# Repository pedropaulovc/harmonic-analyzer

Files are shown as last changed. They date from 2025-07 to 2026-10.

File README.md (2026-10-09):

<h1 align="center">Michelson's Harmonic Analyzer</h1>

<p align="center">
  <em>Learn how to build the beautiful 19th century analog mechanical computer
  that performs Fourier synthesis and analysis via a system of gears, springs,
  levers, and cams. Interact with it in detail both physically and
  virtually.</em>
</p>

<table align="center">
<tr>
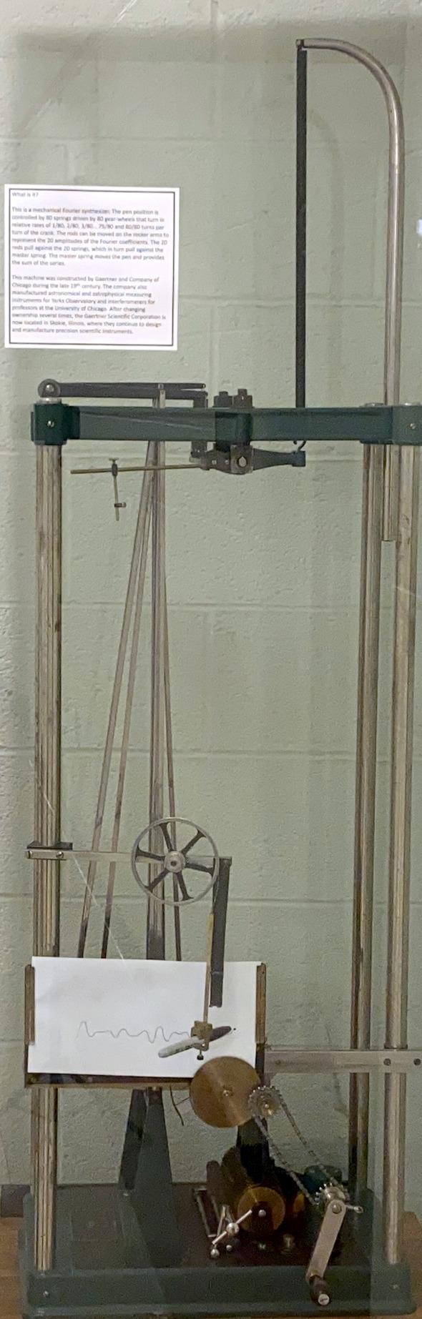
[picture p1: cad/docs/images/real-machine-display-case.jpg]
The surviving Michelson analyzer, stood on end in a glass case at the University of Illinois
<td align="center" width="50%"></td>
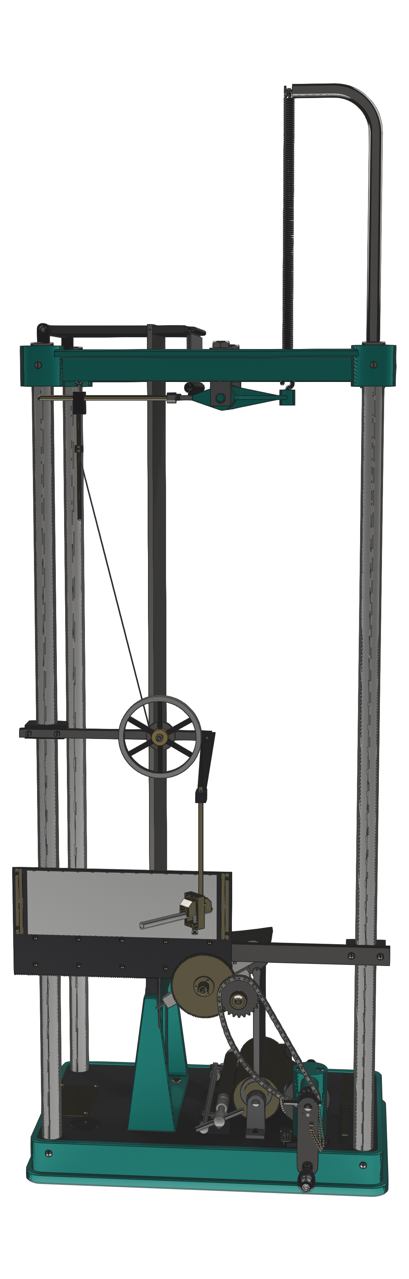
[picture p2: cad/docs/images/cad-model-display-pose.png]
The CAD reconstruction rendered in the same pose
<td align="center" width="50%"></td>
</tr>
<tr>
<td align="center"><sub><b>The machine.</b> The surviving 20-element analyzer, in a corridor case at the University of Illinois.<br>Photographed 2025-08-28.</sub></td>
<td align="center"><sub><b>The model.</b> 149 registered part families, generated from Python, gated on every build.<br>Same pose, rendered from the glTF this repository exports.</sub></td>
</tr>
</table>

<p align="center">
  <a href="cad/">CAD</a> ·
  <a href="book/README.md">The book</a> ·
  <a href="logbook/README.md">Learning</a> ·
  <a href="logbook/progress.md#parts-made">Manufacture</a> ·
  <a href="kickstarter/README.md">Kickstarter</a> ·
  <a href="web/README.md">Website</a> ·
  <a href="ai-story/README.md">Built with AI</a>
</p>
<p align="center">
  Current work and sequencing: <a href="https://github.com/users/pedropaulovc/projects/1">Harmonic Analyzer project</a>.
</p>

---

Turn the crank and the machine performs Fourier synthesis. Twenty weighted
cosines get summed by twenty springs pulling on a knife-edge lever, and a pen
draws the result as a continuous curve. Set it up differently and it runs the
operation backwards, doing Fourier analysis, which Michelson himself declined to
explain on the grounds that it "involves so much mathematics that I shall not
undertake it here."

One of these machines survives in a glass case at the University of Illinois,
and it is very well documented. Bill Hammack, Steve Kranz and Bruce Carpenter
photographed it, took it apart on camera, and published both a book and a
[four-part video series](https://www.youtube.com/playlist?list=PL2FF649D0C4407B30)
explaining exactly how it works. If you want to understand the machine, go read
theirs first. It is free.

What none of that gives you is a way to make one. No dimensioned drawings, no
tolerances, no stock list, no setups, no process. A beautifully explained
machine that nobody has written down how to build.

So: 149 registered part families modelled in SolidWorks, generated from Python, verified on every
build and checked against those same photographs. Plus a book being written to
turn all of that into chips on a shop floor.

## Where it ends up

The finished machine is being donated to
[Matemateca](https://matemateca.ime.usp.br/index_ingles.html), the mathematics
outreach collection at the Institute of Mathematics and Statistics of the
University of São Paulo. They put mathematical objects in front of the public
and in front of students, and they will use this one with middle and high
schoolers. The professor who runs the collection is on board.

It slots into a gap they already have. The collection includes a harmonograph,
Chladni plates, a piece on the harmonic series, one on sampling, and one on
gears, plus an adding machine and a slide rule. What it does not have is the
thing that ties the harmonics half and the analog-computing half together: a
machine that decomposes a curve into its frequencies while you watch.

There is also a line on their donations page that reads, in hindsight, like a
description of this project:

> As there is immense difficulty in finding a professional who can bring object
> theory to practice, the value becomes very variable for each idea. The
> simpler, the lower its cost, which makes it difficult to produce more complex
> parts.

That destination sets the engineering bar. The machine has to work, not
photograph well. A fourteen-year-old gets to turn the crank, and the pen has to
draw the right curve when they do.

## CAD model and drawing coverage

| Frame | Drive train | Channels (×20) | Summing |
|:---:|:---:|:---:|:---:|
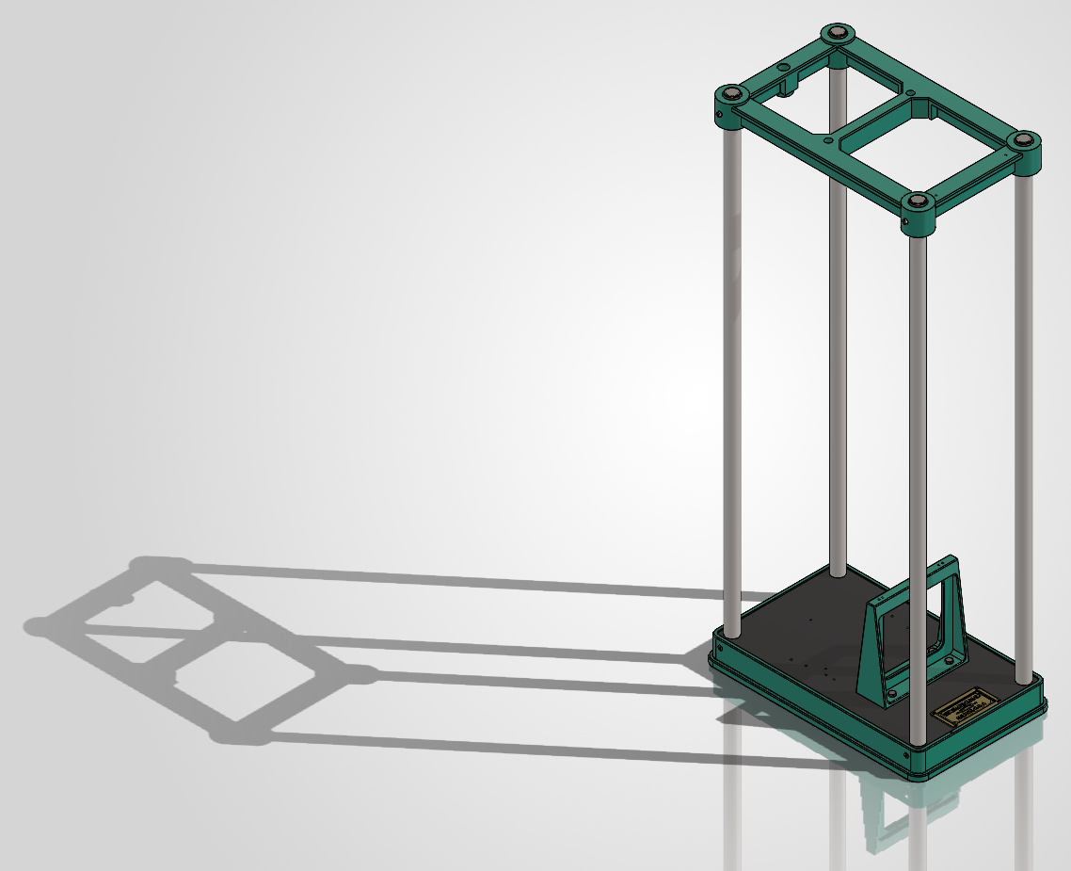
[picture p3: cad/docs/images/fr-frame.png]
Frame sub-assembly
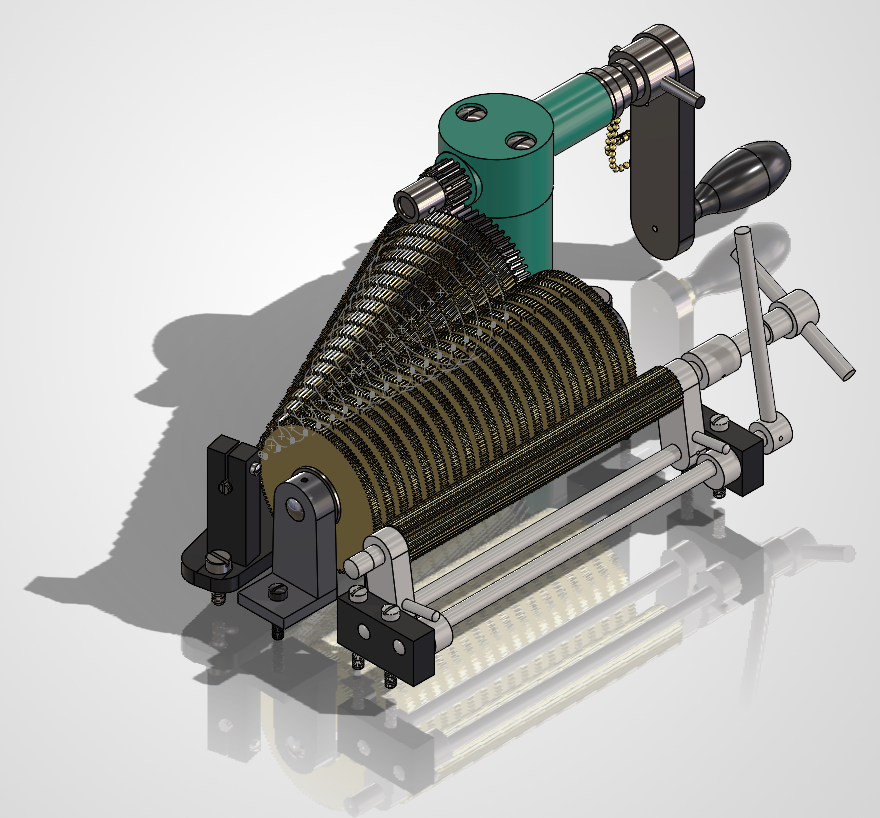
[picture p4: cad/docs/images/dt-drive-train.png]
Drive train: crank, cone gears, cylinder gears
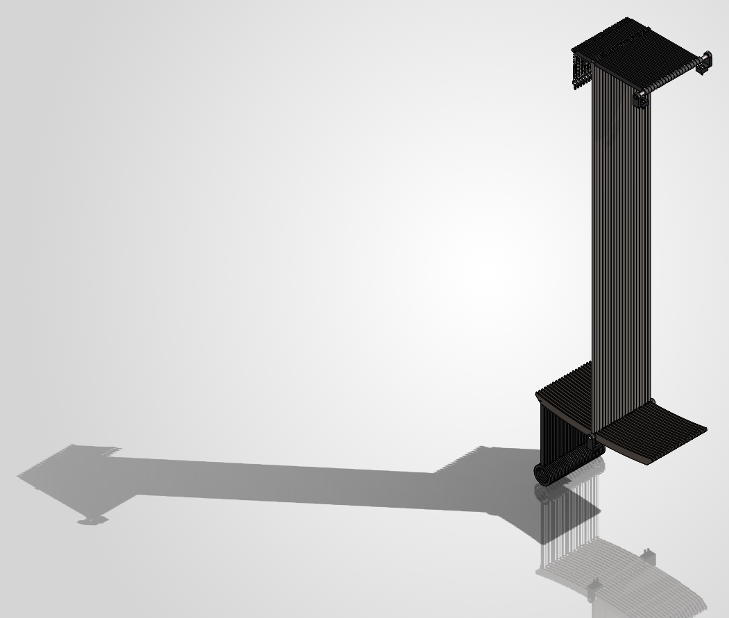
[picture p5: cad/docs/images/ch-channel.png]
Channel: rocker arms, amplitude bars, springs
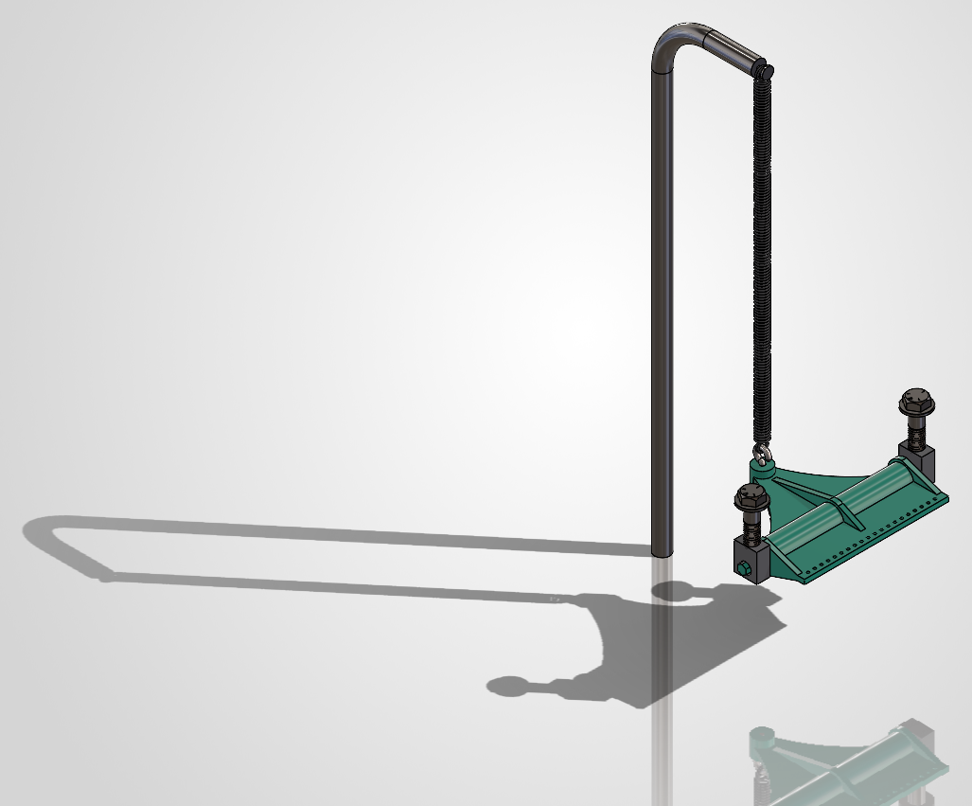
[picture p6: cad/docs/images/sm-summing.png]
Summing: knife-edge lever, counter-spring
|  |  |  |  |

| Magnifier | Pen | Paper drive |
|:---:|:---:|:---:|
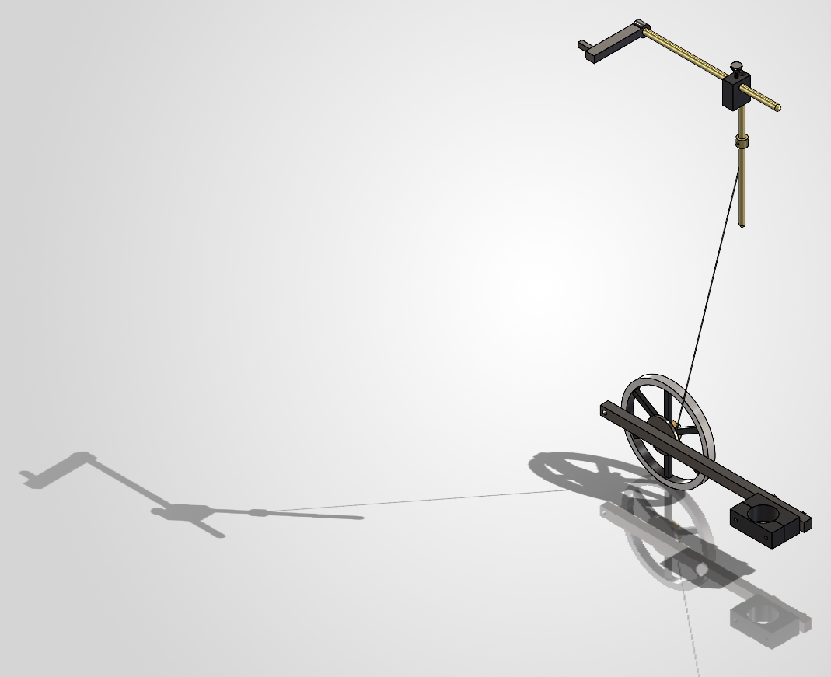
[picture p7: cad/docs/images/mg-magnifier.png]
Magnifier: magnifying lever and wheel
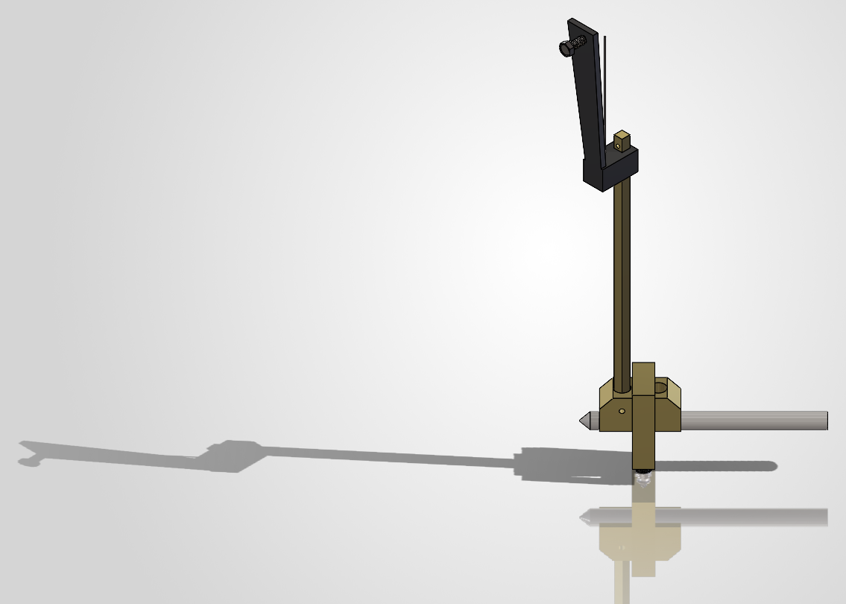
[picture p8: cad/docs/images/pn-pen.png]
Pen carriage
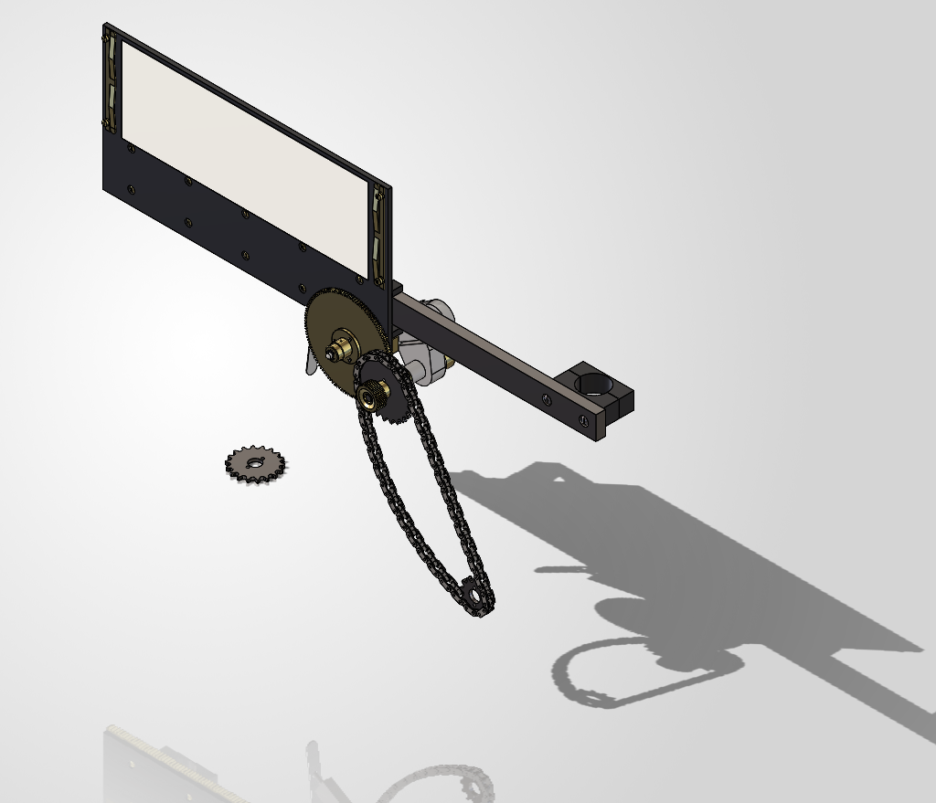
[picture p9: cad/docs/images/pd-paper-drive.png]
Platen, transgear, roller chain
|  |  |  |

Production drawings in the release bundle include both part sheets and
multi-sheet assembly drawings. Here are two part sheets and two assembly-sheet
examples:

| Rocker-arm support | Pinion arbor |
|:---:|:---:|
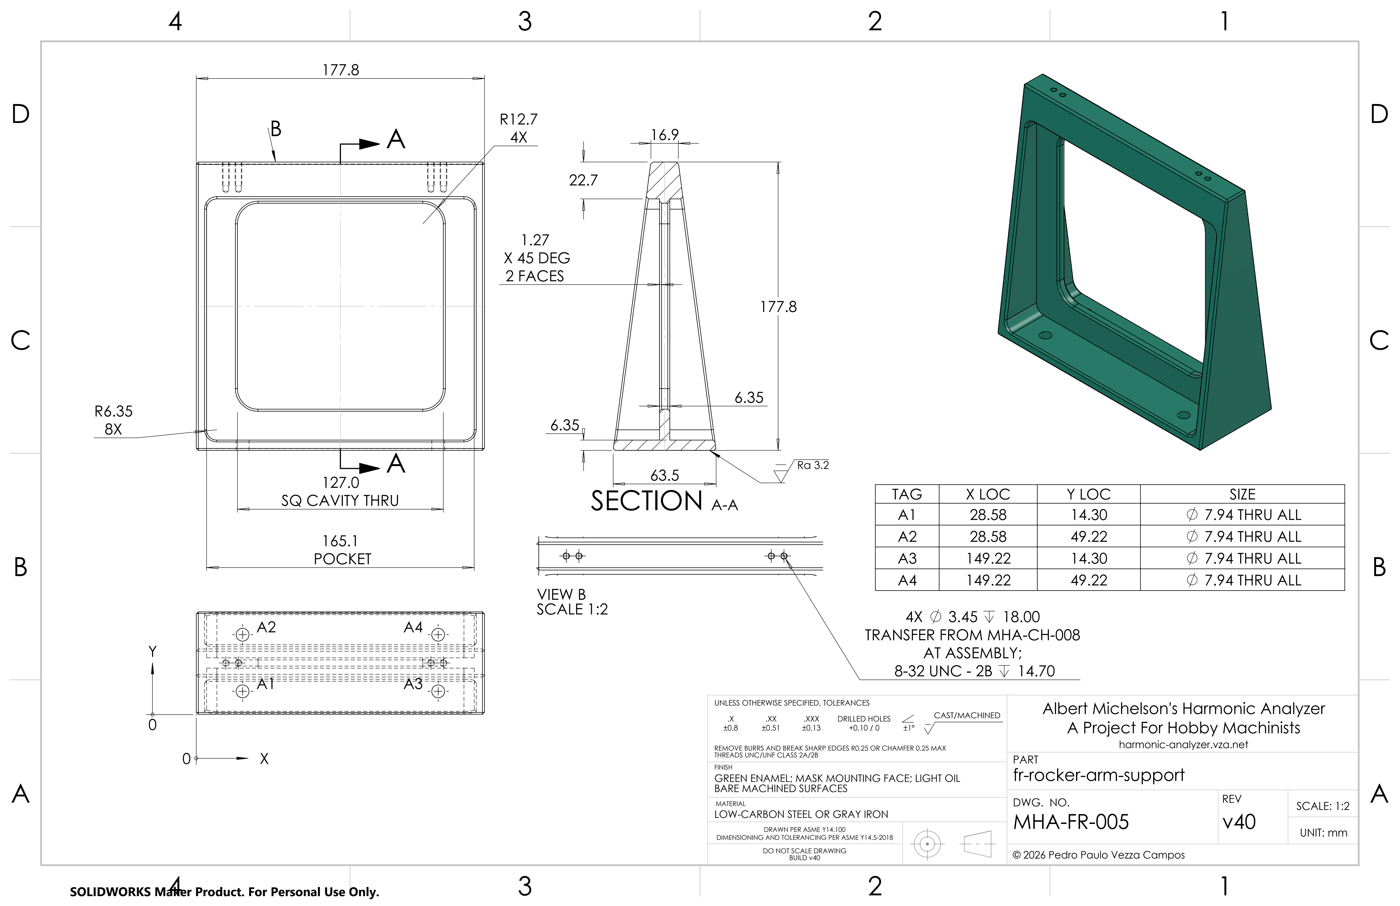
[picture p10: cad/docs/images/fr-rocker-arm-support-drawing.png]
Engineering drawing, rocker-arm support
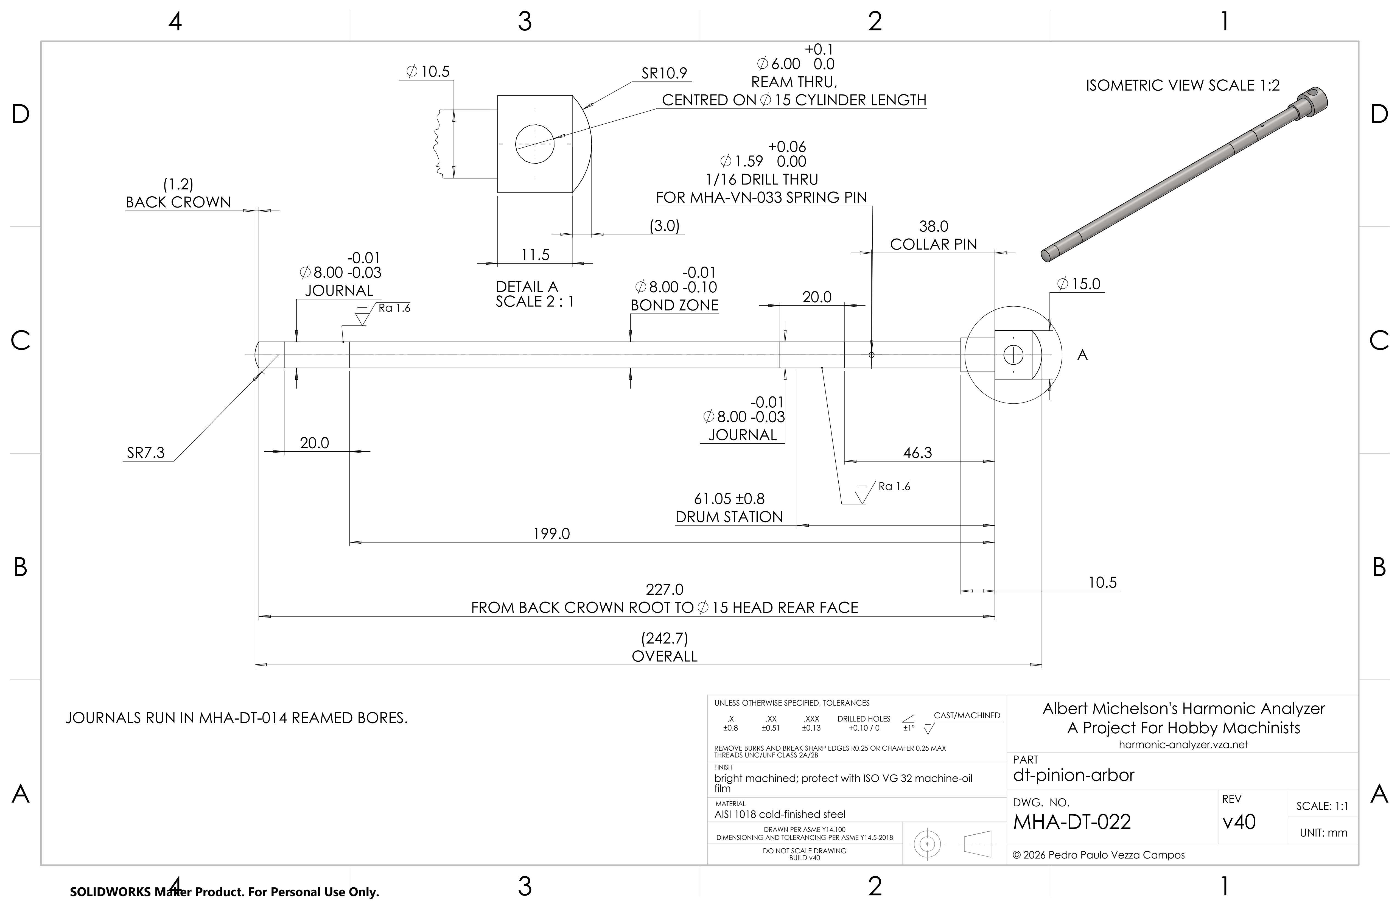
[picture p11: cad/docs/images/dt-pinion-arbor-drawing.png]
Engineering drawing, pinion arbor
|  |  |
| **Drive-train assembly, sheet 4:** Cone Set + Crank Exploded (v39, MHA-A03; now MHA-DT-000) | **Frame assembly, sheet 3:** Match-Fit and Assembly Sequence (v39, MHA-A04; now MHA-FR-000) |
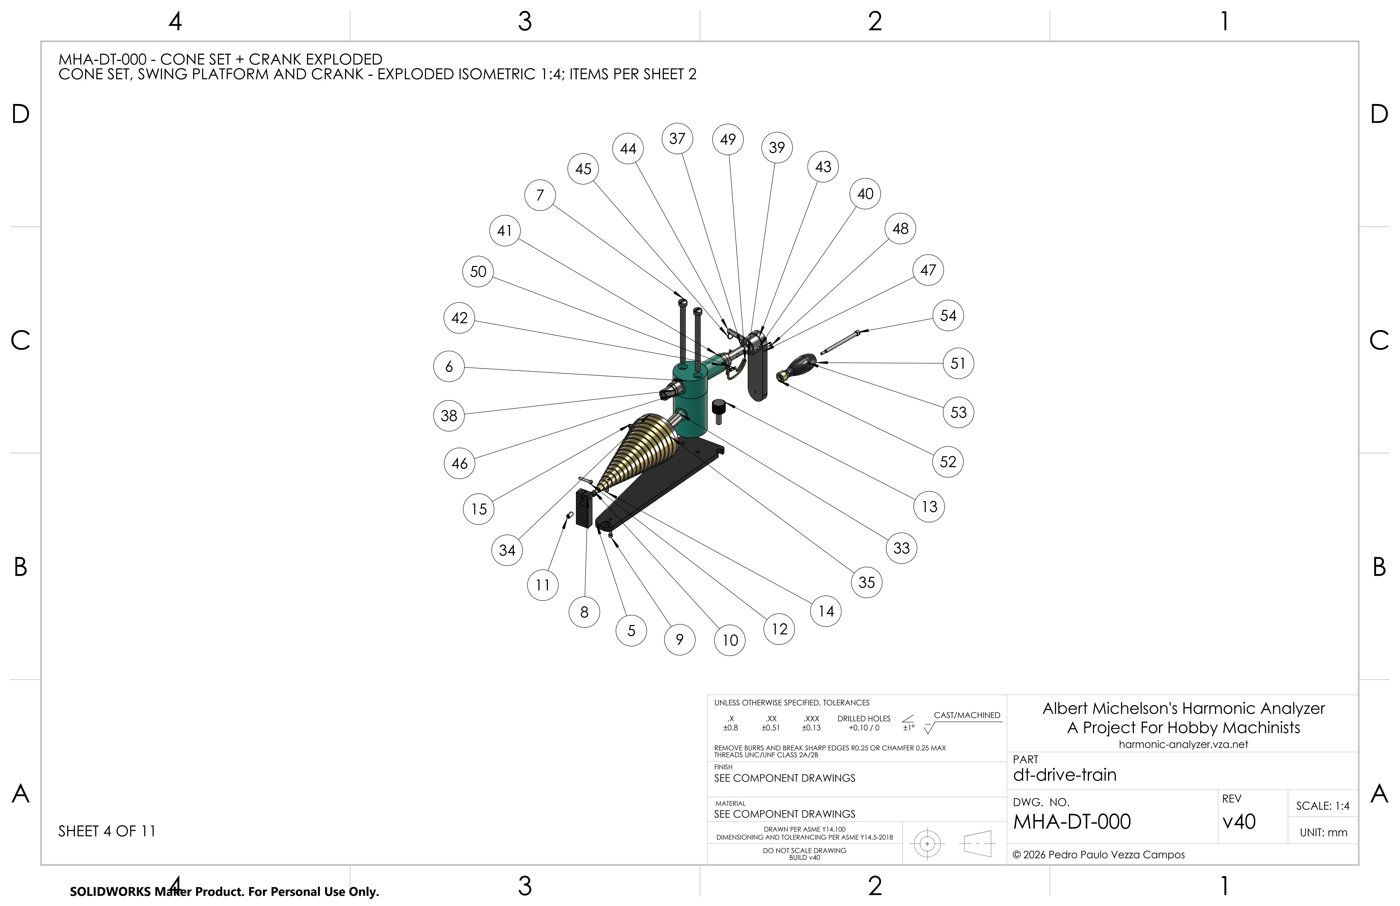
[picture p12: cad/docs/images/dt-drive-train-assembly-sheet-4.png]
Drive-train assembly drawing, sheet 4: Cone Set + Crank Exploded, v39 MHA-A03 (now MHA-DT-000)
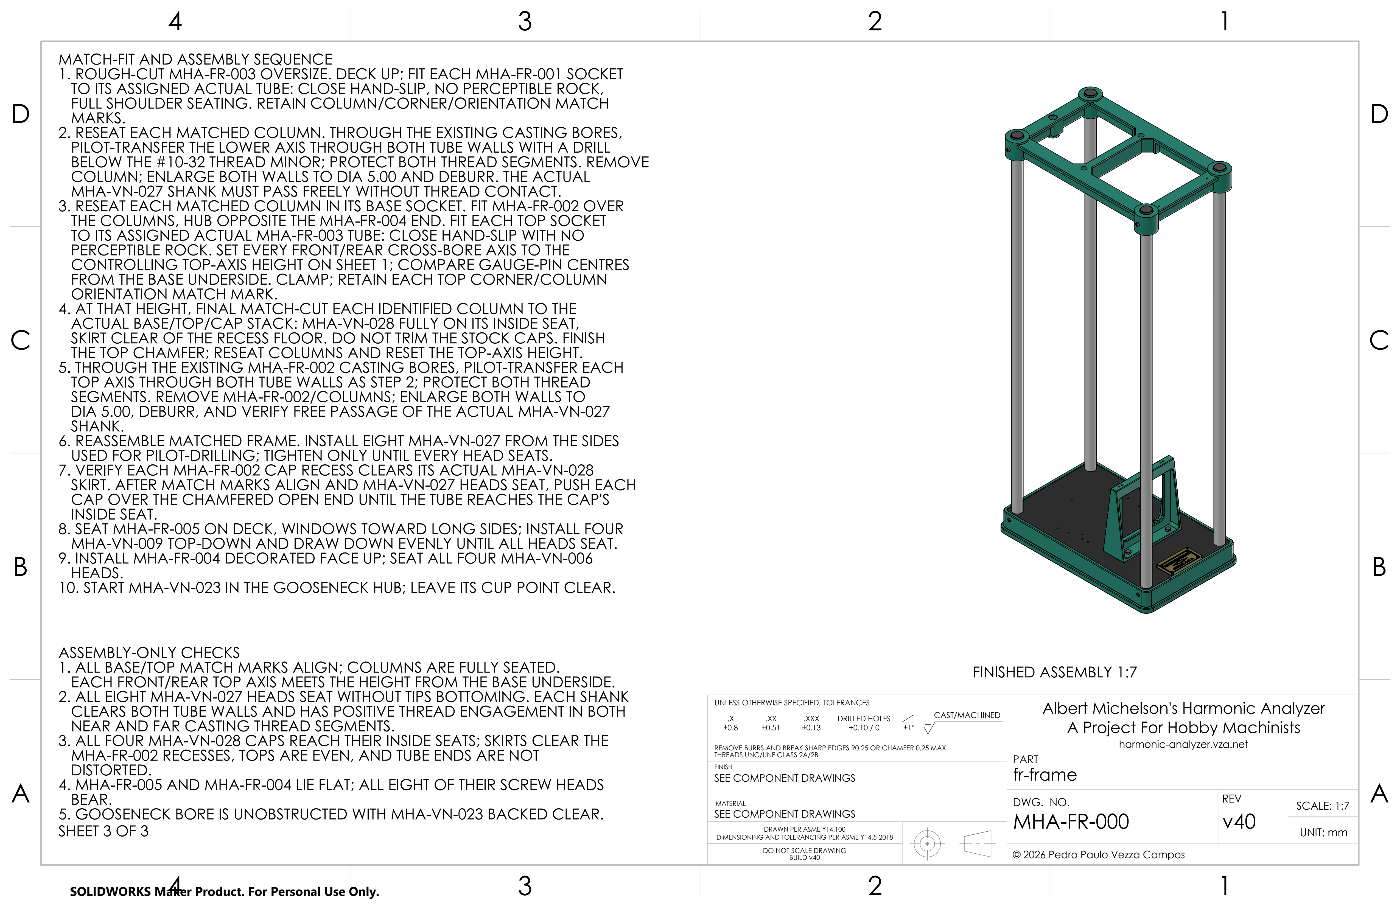
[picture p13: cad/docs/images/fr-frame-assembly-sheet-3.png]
Frame assembly drawing, sheet 3: Match-Fit and Assembly Sequence, v39 MHA-A04 (now MHA-FR-000)
|  |  |

Every part and assembly is generated by Python reproduction scripts in
[`cad/scripts/`](./cad/scripts) driving SolidWorks over its COM API. The scripts
are the source of truth. The `.sldprt`/`.sldasm` files and the renders are build
artefacts, regenerated by `doit` and snapshotted only at
[tagged releases](../../releases).

Every dimension traces back to a source (a book page, a photograph, or a
derivation) and carries a confidence level. Every assembly is gated on degrees
of freedom, interference and mass properties before it is allowed to save. And
the whole model gets scored against Hammack, Kranz and Carpenter's photographs
of the surviving machine, pair by pair, on every export.

Part and assembly filenames carry their subsystem prefix; drawing Numbers use
`MHA-<CATEGORY>-<NNN>`, with `000` reserved for each assembly. The
[subsystem identity guide and migration table](cad/docs/subsystem-identities.md)
defines current names and provides a lookup for identifiers in older releases
and bench records.

## Workstreams

Current portfolio status, priorities and sequencing live in the
[Harmonic Analyzer project](https://github.com/users/pedropaulovc/projects/1).
The repository files linked below hold the detailed engineering and publishing
facts.

| | |
|---|---|
| **[CAD](cad/)** | The generated SolidWorks reconstruction, production drawings, verification and releases. |
| **[The book](book/README.md)** | *A Project for Hobby Machinists*: every part, setup and cut on a manual mill and lathe. |
| **[Learning](logbook/README.md)** | Twelve modules of lathe and mill work, each ending with a real analyzer part. |
| **[Manufacture](logbook/progress.md#parts-made)** | The physical build: accepted quantities, scrap and the entries that record each shop session. |
| **[Kickstarter](kickstarter/README.md)** | Campaign, budget, rewards, assets and fulfilment for funding the build and book. |
| **[Website](web/README.md)** | The machine in a browser, driven by the exported CAD model. |
| **[Built with AI](ai-story/README.md)** | An evidence-backed account of using LLM agents for the project, failures included. |

## The hard parts, which are already identified

A per-part manufacturability pass ([`cad/docs/machining-dfm.md`](cad/docs/machining-dfm.md))
found three parts carrying essentially all of the risk:

- A six-tooth gear about 4 mm across with a 0.49 mm wall at the tooth root over
  a 0.79 mm bore. The hardest part in the machine, and not by a small margin.
- The knife edge, which is the precision interface of the whole instrument and
  sits on a hex trunnion cantilevered 21.7 mm off an organic cast lever.
- A Ø0.79 × 34 mm journal in steel, 43:1 slenderness. Whip city.

There is also one settled finding that shapes the entire build: off-the-shelf
involute cutters for this gear train's pitch do not exist. You make your own.

## Build the model yourself

You need a SolidWorks seat. Full instructions are in
[`cad/docs/BUILDING.md`](cad/docs/BUILDING.md).

```powershell
git submodule update --init --recursive
uv sync
uv run python -m doit          # every part + assembly + every gate
```

Without a seat you can still run the offline gates
(`uv run python -m doit check:math`), and every release ships the STEP, STL and
glTF exports plus the drawing PDFs.

Drawing-bound requirement manifests for the rocker arm, pivot shaft and cone
pivot post are exported with named STEP face sets. Their
`check:traveler_ch_rocker_arm`, `check:traveler_ch_pivot_shaft` and
`check:traveler_dt_cone_pivot_post` gates print the committed process plans through
[prechips](https://github.com/pedropaulovc/prechips); shop blockers are advisory
to this CAD gate, not permission to machine. See the
[export/traveler contract](cad/docs/pipeline/features-travelers.md).

## References

- Hammack, Kranz & Carpenter, *Albert Michelson's Harmonic Analyzer: A Visual
  Tour of a Nineteenth Century Machine that Performs Fourier Analysis*
  (Articulate Noise Books, 2014). Free to read, and the reason this project
  exists at all.
- engineerguy, ["A Machine That Uses Gears to Add Sines and Cosines"](https://www.youtube.com/playlist?list=PL2FF649D0C4407B30)
- Michelson & Stratton, "A New Harmonic Analyzer", *American Journal of Science*,
  fourth series 5, no. 25 (1898): 1–13.

This project is independent of those authors and the University of Illinois, and
is not endorsed by any of them.

## License

Code, CAD and documentation are [MIT](./LICENSE). Reuse of the source book's
content or the video transcripts has to respect their original copyright.

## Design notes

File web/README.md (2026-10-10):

# Harmonic analyzer video companion

Six engineerguy videos share an interactive view of the CAD-exported analyzer.
The original YouTube player sits in the model area's lower-right corner. Pause
for manual exploration, then orbit, pan, zoom, turn the crank or adjust the twenty
channels. Compact mode keeps the same visible player and its audio.

Website workstream status lives on the
[Harmonic Analyzer project](https://github.com/users/pedropaulovc/projects/1).
Implementation and fidelity limits are described in [`DESIGN.md`](DESIGN.md).

## Run locally

```sh
npm --prefix web ci
npm --prefix web run fetch-model -- /path/to/ha-harmonic-analyzer.glb
npm --prefix web run dev
```

The model is a generated artifact, absent from a fresh checkout. Use the exact
raw CAD export identified by `src/mechanics-data.ts`; incompatible bytes are
rejected. `fetch-model` projects native identities through the authoritative CAD
map, performs lossless exact deduplication and Meshopt compression, then publishes
only the optimized GLB. The approved raw export remains unchanged.
It also accepts `cad/out/gltf/ha-harmonic-analyzer.glb` when no path is supplied.
The raw cache stays outside public assets under `web/.vite/model-source/`.
Missing models and failed YouTube playback produce visible errors.

### Fresh-checkout tests and approved model cache

Use Node.js 22.12 or newer, npm and [uv](https://docs.astral.sh/uv/).
The fixture's exact archived CAD provenance commit,
`81539e53f5146c06a77541415bd79da673806d96`, must be available locally: use a
full clone or run `git fetch origin 81539e53f5146c06a77541415bd79da673806d96`.
From the repository root:

```sh
npm --prefix web ci
npm --prefix web run fetch-model:approved
cd web
node --test scripts/*.test.mjs
uv run --isolated --no-project --python 3.13 --with-requirements scripts/source-fit-requirements.txt python -m unittest discover -s scripts -p "test_*.py"
```

The Node command runs all web Node test files; the Python command runs all web
Python test files in an isolated environment with the source-fit dependencies.
These are tooling/geometry tests, not browser source-fidelity acceptance or CAD
builds. `uv` needs Python 3.13 and the listed packages available locally or
network access to install them.

`fetch-model:approved` downloads the already-approved optimized release GLB,
checks its native-source association, SHA-256 and exact byte length, and
atomically publishes it to
`web/.vite/deployment-model/<approved-optimized-sha256>.glb`. It requires network
access to GitHub and the exact approved SHA-named release asset to be published;
unavailable or mismatched bytes fail the command. It does not require deployment
commit/branch identity or Cloudflare credentials, build/deploy the site, or
regenerate raw-model metadata. It does not populate `public/models/` for local
browser use.

Native spring tests use this immutable-hash cache by default. Alternatively,
set `SPRING_MODEL_PATH` to a local file containing the exact approved optimized
GLB bytes before running the Node tests or `npm run test:performance` from
`web/`. Missing or incompatible geometry is an error, never a mock or skipped
test. A populated cache or this explicit path lets the spring tests run without
downloading the model again.

`npm run fetch-model` is different: it imports a **raw CAD export**, projects
identities and generates optimized output/native metadata as described above.
Do not pass the optimized release download to that importer or use it just to
prepare the spring-test cache. `npm run build:deploy` still downloads and
verifies the approved release before running `test:performance`, regardless of
an existing cache or `SPRING_MODEL_PATH`.

### Importing a future CAD release

To adopt a future approved CAD release, provide both its full commit and raw
SHA-256 (not the optimized file's hash):

```sh
npm --prefix web run fetch-model -- /path/to/new.glb --source-commit <full40hexapprovedCADcommit> --source-sha256 <approvedraw64hexreleasehash>
```

The release command reads that exact CAD revision, checks native rest geometry
and compatibility with the website's fixed kinematics, magnifier and spring
deformer mathematics, and stages new native metadata and the optimized asset.
Compatible geometry, rest, spring and setup changes are supported; unsupported
ratio, feed, native-rest association or spring-profile changes are refused with
a named parameter, preserving the last working assets. Missing revisions are
also refused.
A current source commit does not approve arbitrary bytes.
Native identity projection preserves parsed JSON numeric semantics, including
signed zero, and leaves binary geometry untouched. It does not preserve the
original JSON number spelling or integers beyond JavaScript's exact range.
Existing source tracks are stale for a new raw model and reject source-following;
manual exploration is not recalibration. See [`DESIGN.md`](DESIGN.md) for the
representation and provenance contract.

The current imported model is the approved **v39** release: raw SHA-256
`60a62a2edcd15012114d0234438ba54e24be5179f23751ac337cd6df205c562c`,
source commit `81539e53f5146c06a77541415bd79da673806d96`.
The original six source corpora remain archived and hash-sealed. Current v39
records reuse a subset of their measurements, not every historical landmark row.
Migrating those current records preserves their source pixels, PTS, hashes and
uncertainties while rebuilding release-specific tracks from `content/v39-source/`.
Further reuse requires exact exposure provenance and the same physical feature
under a current native association; an unchanged anchor ID alone is insufficient.
Old model-bound tracks remain incompatible, and approximate current tracks do
not establish source fidelity.
No complete current-release source-fidelity acceptance has been established.

Playback can start while the model or source track loads. Source-following starts
automatically when both are ready; pausing retains manual exploration. Status
announcements exclude the running clock. Force readouts are physical calculations,
not source measurements.

The public YouTube player keeps its existing playback and Restore clock contract.
The private local-original player uses visible app-owned play/pause, mute, volume,
scrub and exact-time seek controls. Its safe seek starts at an IDR verified from
the unchanged H264 access units and presents the requested original exposure;
it does not re-encode media or expose an unsafe browser-native timeline.
Local source selection and Restore bind the owned integer PTS/time base and
`requestVideoFrameCallback` frame to the retained authored sample. Native
`currentTime` remains the real model/draw timing clock, not an exact frame ID.
Do not round source timestamps, replace the clock with PTS, or interpolate cuts.

Migration cameras must also be checked against the posed full assembly.
The Intro pen-macro seed was outside the pen frame but looked through the
platen; reversing that chosen camera made the frame visible without hiding
geometry. Visibility is a playback prerequisite, not evidence of a source
pixel fit.

Routes accept a slug or the corresponding YouTube ID:

| Page | Query |
|---|---|
| Intro / History | `?video=intro-history` |
| Synthesis | `?video=synthesis` |
| Analysis | `?video=analysis` |
| Operation | `?video=operation` |
| Machine spin | `?video=machine-spin` |
| Rocker arms | `?video=rocker-arms` |

The PDF page-by-page guide video (`rMHw9GCAtE8`) is excluded by user scope. It
has no route, observation file or verifier page; its MP4 and source intervals
are not acceptance prerequisites.

The video embeds use the official YouTube IFrame API. Downloaded source videos,
reference screenshots and the GLB remain untracked; the site does not host or
redistribute the footage.

### Native calibration inventory

`scripts/export-native-inventory.py` exports the approved raw GLB's unchanged
native rest matrices under canonical qualified paths. It independently checks
the release pair, v2 approval, sole identity map and canonical digest. The raw
GLB and CAD tree remain read-only, including hard-linked output aliases.
Publication replaces the destination entry atomically, preserving any other
hard-link or symlink targets and the previous inventory if writing fails.
The bytes used for the mesh census are digest-bound to the transform input.

```sh
# From the repository root; the approved raw GLB remains private.
uv run --isolated --no-project python web/scripts/export-native-inventory.py \
  --model /path/to/raw-native.glb \
  --source-commit 81539e53f5146c06a77541415bd79da673806d96 \
  --expected-model-sha256 60a62a2edcd15012114d0234438ba54e24be5179f23751ac337cd6df205c562c \
  --output /tmp/v39-native-model-inventory.json
npm --prefix web run test:inventory
```

The v39 artifact has 457 released descendant transforms: 450 mesh nodes and
seven assembly transforms. Its mesh primitives produce 460 native drawables.
The assembly root, camera and runtime-generated spare instances are not
inventory rows. `fit-source.py` consumes the matrices as column-major
part-local-metres to native-world-metres, and checks the original raw-model
digest before using any landmark. This inventory does not supply source
observations, camera calibration, motion evidence, historical bounds or
source-fidelity qualification.
General affine matrices remain unchanged. The v39 rest matrices are rigid within
1e-6 orthogonality/determinant tolerance; rotational overrides in the fitter
assume rigid rest transforms and are not qualified for scaled or sheared inputs.

The inventory tests are enrolled in `test:model`. They are web-only tooling,
not CAD/doit tests; their independent transform and immutable-input controls
run without SolidWorks, a GPU, source footage or the private GLB.

## Canonical identity evidence audit

`content/canonical-native/manifest.json` seals 29 identity-only derivatives.
The sole mapping authority is `../cad/config/identity-migration-map.json`.
Original evidence files and `canonical-native/historical-code/` snapshots are
immutable inputs; the offline audit never executes archived producers, fetches
network data or recovers files from Git.

```sh
npm --prefix web run verify:identity-evidence
# From web/: read-only seals and deterministic byte replay
uv run --isolated --no-project python scripts/canonical-native-evidence.py validate
uv run --isolated --no-project python scripts/canonical-native-evidence.py check
# Explicit authoring only, after an intentional mapping/input change:
uv run --isolated --no-project python scripts/canonical-native-evidence.py generate
```

`verify:sync` runs the identity evidence check first. Both read-only commands
check exact original, derivative and historical-snapshot SHA-256 seals,
CRLF-to-LF-normalized current-consumer input seals, original numeric-token
certificates, dependency pins and deterministic
replay. `generate` rewrites only declared derivatives, current SHA pins and
the manifest's existing seals. JSON numbers are never parsed as floating-point
values; all original numeric lexemes remain byte-identical. The six observation
derivatives additionally remove only JSON whitespace outside quoted strings and
have exactly one decoded EOF newline. They are stored as deterministic
`*.observations.json.gz` files; current generators and verifiers decode gzip.
The manifest seals both stored bytes (`sha256`) and decoded bytes
(`decodedSha256`). Gzip uses compression level 9, zero timestamp and no embedded
filename. Historical capture commands keep their recorded plaintext paths;
they are provenance, not current loader aliases. Evidence paths are translated
only for declared
manifest members; authored source tracks remain directly under `content/`.
Path/hash projection updates explicitly current regeneration inputs and the three
current `sourceObservations` metadata fields. Required producer-code records must
declare their usage. `historical-producer-lineage` retains its recorded SHA and
an exact commit/source-path/hash-addressed snapshot origin; it is never re-sealed
against a changed live classifier. The nine original-capture snapshots and three
prior identity-migrated input snapshots have distinct provenance. Duplicate
projection containers or authority members are ambiguous and refused; unrelated
capture duplicates remain byte-exact.
Inactive inputs do not authorize path/hash projection; their captured duplicates
remain uninterpreted even when a neighboring current input is updated.
Sealed canonical files are exempt from Git newline conversion. Replay preserves
the original non-observation whitespace bytes; observation packets use the
compact LF form above. Do not convert sealed derivatives to checkout-native
CRLF: dependency SHA pins refer to their exact replay bytes.
The manifest explicitly declares `canonicalConsumerHashNormalization` as
`CRLF-to-LF` for editable current code/data inputs only. Their hashes certify
the normalized text, not checkout byte identity. Original evidence, historical
snapshots, mapping bytes and derivative dependency pins are never normalized.

Direct Node track-association readbacks invoke the same standard-library
publication-seal checker through `uv run --isolated --no-project python`, not an
ambient `python3` executable or a separate interpreter configuration. Exact
record bytes, current native/assembly authority and live generation seals
remain required.

Ordinary producers for all six videos read only strict
`content/v39-source/<ID>.observations.json.gz` records. They validate the current
tracked representation authority, original MP4 identity, native inventory/map
association, exact camera/source exposure bindings and complete chosen physical
inputs. Construction, build and publication re-read the relevant live seals and
the compressed/decoded observation byte seals; a historical snapshot cannot
replace a missing or changed live input. Pair CLIs build and prepare both tracks
before publishing either output.

Analysis/Synthesis historical replay is separate:
`HistoricalReceiptRevalidator.revalidate_receipt()` checks immutable historical
packets and sealed producer/math snapshots. Its non-publishable receipt is not a
current source track and cannot grant current eligibility.
The same revalidator can replay repeatedly: retained camera/input numbers remain
sealed, while framing application counts describe each individual replay rather
than accumulating across receipts. Validation does not append native exposure
keys to the initialized observations.
The original-native Analysis bank extraction, visible-crank gauge, Synthesis automatic-motion and
Spin mechanics CLI implementations are retired from `scripts/`: their required
historical native tuple is not the current live tuple. Original producer source
remains in the SHA-addressed `content/canonical-native/historical-code` archive,
not as an executable current-native replay or fallback.

For current observations, an omitted landmark `viewId` belongs to `main`.
Present landmark and unavailable-row scope IDs must be strings; explicit `null`
is not an omitted scope and is refused by the runtime contract.
Fitting and observer availability apply that default at the consumer boundary;
they do not rewrite the original source measurements or explicit view scopes.

Historical source diagnostics write only to resolved
`web/.vite/verification-output` or external destinations under the platform-native
temporary directory (`tempfile.gettempdir()`), `/tmp` or `/var/tmp`.
Public assets, other repository destinations and symlink escapes are refused
before generation. Their receipts remain non-publishable historical evidence.
All historical diagnostic CLIs write through exclusively created staged-file handles,
flush and sync them, then atomically hard-link the completed files to pinned,
validated paths. Existing files, symlinks (including dangling links) and reparse-point
entries are never overwritten. The crank extractor also
creates its support directory exclusively, refusing existing directories and
symlink/reparse-point entries.
Ordinary current observation outputs remain rerunnable: the observer and fitter
write deterministic gzip through an exclusively created temporary file in the
validated parent, flush and sync it, then atomically replace the pinned destination.
A leaf symlink introduced at replacement is replaced, never followed.
Temporary roots and output paths are resolved before comparison, including platform symlinks.
The entire checkout remains excluded from external temporary permission even
when the checkout itself is under a temporary root; private-root symlink escapes are refused.
The observer, fitter and remaining historical diagnostic CLIs share
`check_namespace()` from `fresh-source-observations.py`. The historical CLIs use
their already-loaded `common.fresh` policy. Declared content aliases are refused
even when they resolve to external temporary files; historical snapshots are not
live policy fallbacks.

Immutable original observations and canonical derivatives retain their exact
Git bytes through `.gitattributes` (`-text`), including on Windows checkouts.
Raw evidence seals do not permit newline normalization; CRLF-to-LF normalization
belongs only to current consumer code/data seals.

Compression reduces current storage, not Git ancestry. Oversized historical
blobs remain unless history is explicitly rewritten.

Native bindings use explicit root/component or root/assembly/component forms,
with optional structural `/mesh` or indexed `/mesh_N` leaves. Identity and
instance suffix translation uses the sole map; unsupported segments fail closed.
The qualification-case `nativePartPaths`/error fields may contain mapped-stem
`-*` family selectors, not concrete drawables. An unbound visible-motion feature
(`partPath: null`) may retain a well-formed numeric `candidatePartFamily` range:
only its declared root/assembly translate; its opaque historical family symbol
is not promoted to a current part identity. The source-backed spare-sprocket
`@upper`/`@crank` consumer-instance suffixes remain intact. These semantic forms
do not permit unknown concrete `partPath` bindings or general suffix aliases.
Qualification-case `negative-native-` names embed the corresponding native
locator after that schema-specific prefix and translate it as a concrete
binding. Historical localhost web-route commands are not native CAD locators
and retain their original route spelling.
Inventory includes those schema-specific labels, not lookalike prose elsewhere.
Before replay returns any output (and before `generate` writes), all 29 original
members are inventoried. One failure packet lists every undeclared occurrence
in source-path/traversal order with its exact JSONPath, binding and reason;
duplicate object members and occurrences remain distinct. Keys and values are
decoded for escaped slashes. This diagnostic walk retains numeric lexemes as
strings and never authors JSON; output still uses lexical string-token rewrites.
Only exact existing archived-binding entries receive `archived-not-current:`.
Byte-replay failures list every mismatching derivative path, rather than
stopping at the first packet.

These certificates establish identity/provenance preservation, **not** fresh
geometry, source-camera or browser qualification. The approved v39 raw export
can supply canonical identities through the importer; a newer CAD export is not
required for renaming. Mechanics/magnifier regeneration and native/browser
qualification remain separate gates. There is no runtime old-to-new GLB alias,
and projecting identities does not make historical observations current.

## Fidelity and verification

The interactive mechanism uses CAD-derived eccentric cams, connecting rods,
finite rocker arcs, amplitude bars, twenty loaded extension springs, the counter
spring, wire and magnifier. It solves quasistatic torque balance. It does not
simulate tooth collisions, friction or inertia. The amplitude controls show CAD
station millimetres; calibration to the video's engraved measuring sticks is
not established.

Historical projection and GPU evidence described below belongs to the earlier
model. Its measured results and chosen settings do not qualify the v39 scene;
source-only measurements remain archival evidence. Promotion into a current
record additionally requires exact exposure and current-feature correspondence;
archival completeness does not imply every measurement is reused in v39.

Source-following tracks combine source cameras with complete feasible physical
inputs. Hidden settings may be chosen and are labelled unobserved, not recovered
historical settings. Playback distinguishes a working approximation from measured
fidelity. Unsupported required intervals remain explicit; intervals without a
corresponding machine may retain the preceding pose.

Analysis03's bounded interval **4.4044..7.307300000000001 seconds** and
Synthesis's presenter-to-spin interval **25.984291667..26.609916667 seconds**
opt in to chosen continuous camera framing at both endpoints. Position,
rotation, FOV and principal point blend only within compatible same-shot views;
Synthesis's existing front-camera position/rotation stay fixed while its chosen
principal-point/FOV keys reframe the single machine image. Cuts, layout and
discrete mechanical changes still hold the decoded exposure. This is unmeasured
source-informed framing, not recovered camera history or a fidelity pass.
The current **50% / 0.5-second** target and other videos' policies remain unchanged.

The optional `content/canonical-native/<videoId>.chosen-camera-continuity.json` permission packet
pins source SHA, shot bounds, native coverage and unmeasured main/whole framing
evidence. No packet preserves the old policy. Analysis03 retains all 90 source
observation rows covering the contiguous native exposures 132..218. Synthesis's
presenter-to-spin retains 16 rows covering all 15 native exposures 623..637;
source cameras in both intervals remain null. Only the selected families bypass
the producer's generic 30-degree branch split; generated framing keys are not
new measurements. The Synthesis **25.98..26.54-second** scoped headless
demonstration does not qualify source matching or recover camera/mechanical pose.
Before Synthesis's existing single-main normalization, selected permissions
refuse original measured, partial-frame, mirrored, warped, composite, missing,
empty or unmapped views. Valid null-camera full-frame main or outgoing/incoming views
remain accepted; normalized main framing is checked afterward. Original retained
source layouts are not edited.
Regenerate either video independently with
`uv run --isolated --no-project python web/scripts/generate-analysis-synthesis-source-tracks.py --video 6dW6VYXp9HM`
or replace the video ID with `8KmVDxkia_w` for Synthesis.
Omitting `--video` still validates and prepares both Analysis/Synthesis outputs
before publishing either.

Immutable historical Analysis packets retain bounded cumulative source-drive
evidence for the visible crank (79.8130667..86.6866 seconds) and mirrored bank
(112.3122..119.0856333 seconds):
[`6dW6VYXp9HM.visible-crank-motion.json`](content/canonical-native/6dW6VYXp9HM.visible-crank-motion.json),
[`6dW6VYXp9HM.visible-crank-gauge.json`](content/canonical-native/6dW6VYXp9HM.visible-crank-gauge.json),
[`6dW6VYXp9HM.automatic-motion.json`](content/canonical-native/6dW6VYXp9HM.automatic-motion.json)
and [`6dW6VYXp9HM.motion-controls.json`](content/canonical-native/6dW6VYXp9HM.motion-controls.json).
They separate observed relative motion from chosen native sign/home and hidden
setup. Historical receipt revalidation retains same-shot margin holds and
original gauges; ordinary current playback instead consumes the fresh records
above. [`DESIGN.md`](DESIGN.md#bounded-analysis-motion-authority) describes the
historical evidence and private source-only flow. These historical drives remain
chosen approximations; source camera and geometry fidelity are unaccepted.

Synthesis's immutable historical rocker-bank interval **105.980875..124.4159583 seconds**
is retained in [automatic-motion inputs](content/canonical-native/8KmVDxkia_w.automatic-motion.json)
and [source evidence](content/canonical-native/8KmVDxkia_w.automatic-motion-evidence.json).
Their original producer bytes are archived for lineage, not a current-native
canonical regeneration command. Historical receipt revalidation consumes these
packets; ordinary current track generation consumes only fresh current records.
The source's 4× label describes published-video playback: mean cadence is
1.559234652 turns/s, with unsigned cumulative drive of 28.744620749 turns across
410 native knots. `bank-direction-+1` is an explicitly chosen physical direction,
not a recovered historical sign. Twenty constant common upper phases remain a
chosen prior; hidden amplitudes and setup remain chosen and unmeasured.

This drive applies only to the rocker-bank/main/native full-canvas unwarped view.
Unmeasured same-shot slivers hold the nearest new input until the real cut.
The lower-crank interval **270.35..271.23 seconds** is excluded
(`phaseMatchQualified: false`); cadence and phases do not transfer across cuts.
Conditional actual-metal controls cover **18 held-out exposures at H20**
(maximum 26.50 px) and **17 pixel/feature-held-out exposures at H1**
(maximum 9.43 px). H20 CHECK exposures are disjoint from annotation FIT.
H1 CHECK times overlap annotation FIT, but its cross-feature physical pixels
never enter the cadence or H1 pixel-gauge fit. H2–H19 remain unmeasured.
They do not qualify GPU motion, the full scene or the camera. Separate native
GPU captures exercised all twenty visible rocker meshes, with changing raster
extents and contours at a fixed camera. Uninterrupted original-video/native
playback had a maximum 52.690 ms media-to-completed-draw skew. The fixed far
portrait camera still mismatches the filmed bank close-up; camera and geometric
fidelity remain unqualified.

`npm --prefix web run test:playback` exercises eight synthetic runtime decisions
through Vite SSR, without a browser or GLB. `SOURCE_TRACK_MODULE` may point to
a historical source-track module for a failing-before control; these tests
do not measure source fidelity.

The filmed U-shaped connecting-rod junction and the native plate-like head are
treated as functionally equivalent for animation, with the user's approval
pending a later CAD correction. The HUD and verification reports retain this
head-shape assumption. Other motion, camera and geometry checks still apply.

The user separately allows a narrow exception for only the two small
rimmed/recessed lower-rocker side-face features either side of the fulcrum.
They are absent from all twenty native rockers and remain explicitly
**uncertified**, not pending a promised CAD correction. The closed declaration
names both exact source features and only `ha-harmonic-analyzer/ch-channel/ch-rocker-arm-1..20`
paths. The HUD identifies this exception separately from the rod-head mapping;
reports retain both exact records when declared.

Neither exception establishes correspondence for an entire moving part. No source
pixels, native holes or textures are fabricated. The native inventory and coherent
mechanism motion remain required; per-part source certificates at every exposure
are no longer prerequisites for approximate playback.

Structural fixed parts that the source cannot identify may remain rendered in
a complete feasible reconstruction, with the user's approval. They are listed
as source-non-identifiable, not geometric-fidelity passed. Identifiable-feature,
rendered-pixel and actual-clock checks retain their requirements; motion and phase
classifications remain explicit diagnostics, not per-image certificates.

The current plan is **50% of source frame width across all six videos**, followed
by a working browser demo. This is a maximum scored landmark error, not a fraction
of coverage. At 1920 pixels wide the limit is 960 pixels; timing remains within
0.5 seconds. The 20%, 10% and 5% refinement stages are outside the current request.

Complete coarse visual matching across the collection, then demonstrate the
implementation. Verify every required integer second and visible change using
spatially distributed, independently measured source CHECKs associated with the
current native geometry, actual rendered pixels and visual overlays. Close-ups,
insets and montages remain required. Fixed/moving composition, a counterfactual
point-motion witness and a static-rig certificate are not prerequisites for this
visual-and-timing scope. Unknown motion or phase stays unknown in diagnostics;
it does not waive source pixels, current geometry association, physical
feasibility, raster visibility, the 960-pixel limit or the 0.5-second clock bound.
Optional finite native LINE checks retain their fixed-body eligibility; a posed
ruler cannot supply a fixed BODY LINE check. Report uncertainty, exceptions and
unavailable measurements explicitly. A passing subset or missing source CHECK
pixels is not an all-six stage-50 pass.

```sh
npm --prefix web run build
npm --prefix web run preview

# Current all-six coarse collection; no video/time scope or optional eligibility:
HARMONIC_HEADLESS=1 npm --prefix web run verify:sync -- --stage 50 --player local

# After the all-six coarse pass, demonstrate the unchanged private original footage:
npm --prefix web run preview:reference -- --port 5967
# http://127.0.0.1:5967/harmonic-analyzer/?referenceMedia=1
```

`HARMONIC_REFERENCE_ROOT` defaults to durable ignored `web/.vite/reference-root`.
It must contain the six original MP4s under `videos/`. `preview:reference` serves
them locally with range support without copying footage into publication assets.
Default public playback remains the official YouTube embed.
The verifier serves `dist/`, exercises the original media, and reports per-video
coverage, rendered landmark errors and timing. The current collection command
must explicitly select stage 50 because the CLI retains its existing finer-stage
options/default; those are not queued deliverables. Clock skew remains at most
0.5 seconds, and manual operation, native media audio state and compact playback
remain required. No audible-speaker observation is implied by media-state checks.

**Measured checkpoint (2026-10-08 UTC).** The unscoped all-six
`--stage 50 --player local` run at `4cfeaee9373d6e78305e39390f2cc608c12f9aaa`
finished **unavailable**, exit 1, with the actual RTX 3090/D3D12 renderer on
every route. It selected every mandatory census key, but selection is not
independent landmark coverage:

| Video | Required samples containing measurements / required | Passed required samples | Maximum measured error (px) | Maximum measured clock skew (s) |
| --- | ---: | ---: | ---: | ---: |
| Intro/history | 1 / 1212 | 0 | 453.373 | 0.018600 |
| Synthesis | 11 / 629 | 9 | 384.221 | 0.041708 |
| Analysis | 91 / 365 | 78 | 289.864 | 0.016684 |
| Operation | 2 / 1019 | 2 | 50.874 | 0.450450 |
| Machine spin | 2 / 186 | 2 | 73.752 | 0.437938 |
| Rocker arms | 1015 / 1153 | 984 | 32.765 | 0.020834 |

The error maxima include admitted mandatory and diagnostic measurements; they
do not bound unmeasured frames. A sample containing FIT pixels can still lack
independent CHECKs. All six stage summaries remain unmeasured, not accepted.
The run retained missing/unsupported source checks, two Analysis spring-bound
refusals at 113.8137 and 119.08563333333333 seconds, compact-playback failures,
and Analysis/Spin manual-setup decode errors before any crank/orbit exercise.
The original compact-failure predicate values were not saved; subsequent
diagnostic receipts retain actual media/render values before the unchanged
0.3-second advancement and 0.5-second clock assertions.

A separate fresh-page headless smoke at the same checkpoint passed on all six
pages: real paused crank/orbit/pan/zoom, clock-bound Restore of camera/input/
assembly, visible 222×200 original-media native controls, unmuted volume 1,
and advancing current native draws. Its maximum observed playback skew was
0.013994 seconds. Intro also recovered the actual EOF HUD and preserved ongoing
manual crank motion through a paused native seek. These bounded positives do
not clear the collection failures, certify missing intervals, demonstrate speaker
output, or exercise the official provider in this round.
Private source/data/dist seals, complete reports and screenshots are retained in
`web/.vite/complete1227-stage50-20261007/`; they are not publication assets.
Later code/seal changes do not relabel this frozen report as newer-head scoring.

After the repeatability correction and consumer-seal refresh,
`3cfa8f6dd7848020d85079124eb6517d5a1da74e` passed a separately bound fresh
six-page runtime smoke, with maximum observed playback skew 0.015018 seconds.
All observation, track and compiled-dist bytes exactly matched the frozen
checkpoint. A single changed-diagnostic Synthesis arm at 284 seconds retained
the actual compact failure: 0.227414 seconds of native progress after 600 ms,
below the unchanged 0.3-second minimum. Media was unpaused, unmuted at volume 1,
readyState 4 without an error; source following and the 0.009989-second model
skew passed their existing predicates. That time-scoped diagnostic is not an
acceptance run; its short-window failure and the original collection failures
remain failures despite the longer bounded runtime positives.

The bounded native-progress correction replaces the fixed 600 ms observation
with a wait for the same 0.3 seconds of actual source progress, using the existing
20-second timeout. Unmuted positive-volume media, the actual native button,
source following, at most 0.5 seconds of clock skew and a new current native draw
remain required; timeout/error receipts retain their real predicate values.
The changed Synthesis 284-second arm passed with 0.312458 seconds of source
progress and 0.010537 seconds of clock skew. A real original-media pause before
the boundary advanced only 0.000037 seconds and was refused by the 20-second
guard. A fresh six-page compact/manual/Restore smoke passed with maximum observed
skew 0.012847 seconds. These separate receipts are under
`web/.vite/complete1227-stage50-20261007/native-progress/`; they do not rewrite
the frozen scientific report or clear unexercised collection failures.
Restore equality binds camera, input and assembly to the measured native clock;
`currentTime` alone does not identify the exact presented decoded frame.

The first ordinary collector for the next integration, frozen at
`53863496a52d87a02a10a2beb8006cd039a97954`, scoped Operation to 204 seconds
and remained **partial/unavailable**, exit 1: **0 of 1** selected required
samples measured, out of **1019** required collection samples. Its old seek
observer expected `seeking`/`seeked` at the target, whereas the safe player
actually seeks to a verified IDR and then presents the target. Compact discovery
also mistook `media.controls === false` for missing controls despite the visible
app-owned original-media controls. Six preceding ordinary playback draw/clock
brackets passed with observed skew zero; they do not clear those failures.

A separate single real pointer seek on the same frozen ordinary build presented
Operation frame **6114**, integer PTS **6120114 / 30000**, at rVFC time
**204.0038 seconds**. Native `seeking`/`seeked` occurred at IDR time **200.5003**;
the actual paused model/draw/media clock was **203.985846**, not rewritten to PTS.
Unchanged full `measureView` admitted six independently measured main-view
CHECKs, maximum **81.56609 px**, with native/model skew zero. Four old FITs were
excluded for missing edge provenance, and fixed/moving classification remained
unavailable; this is not a required-sample or source-fidelity pass. The unchanged
half-frame timing assertion passed on that packet. Its one offline invocation
on an older genuine raw receipt threw at **0.031493 seconds** of PTS/clock
difference, but that older receipt lacks the real URL/epoch and DOM-canvas fields
needed for full ordinary-consumer qualification. Both outcomes remain separate.
Immutable receipts are under
`web/.vite/stage50-refinement-20261008/`; the new collector must bind owned
original frame identity separately from the unchanged 0.5-second clock limit,
and exercise the actual visible app controls without weakening source floors.

Original-source authority is validated before lazy shared browser startup. Shared
startup becomes ready only after server, browser, context and page acquisition;
failure is one terminal verification prerequisite with acquired-resource cleanup,
not repeated per-video launch attempts. Missing originals remain per-video failures.
Verification-only publications use detached banks: ordinary playback and trusted
manual/layout intent resume the real frame rather than inheriting a diagnostic
candidate. Scoped diagnostic APIs expose guarded methods and detached data, not
live mutable model/viewer handles. Pending or expired publications refuse instead
of rolling back newer state. Failed restoration invalidates source/physics/draw
claims while independent cleanup still runs. See
[`DESIGN.md`](DESIGN.md#browser-verification) for ownership and unexercised
failure-path limits; diagnostic controls never qualify source fidelity.
`?verify=1` enables native WebGL landmark readback. Mathematical camera fitting
alone does not count as rendered-pixel evidence.
Diagnostic landmark receipts also retain the actual native marker's world
coordinates from the same completed view draw. Stale, unresolved or
GPU-deformed coordinates remain unavailable; world coordinates are not
source-pixel measurements or camera qualification.

Optional native eligibility requires `nativeViewportBackingPixels: null` for
unwarped captures and current native backing dimensions for warped captures.
A refused diagnostic lease preserves its original unavailable reason and partial
snapshot/capture evidence; unrelated cleanup failures still propagate. Neither
collection nor a successful metadata join qualifies source fidelity or GPU bounds.
The optional classification is scoped to
`selected-native-stage-pixel-exact-vertex-identity`, not general native-anchor
visibility or validity. A quantized pixel-centre ray can hit an incident native
triangle while exceeding the unchanged 1e-7 m distance to its exact stored vertex
class; tiny nonzero pixel-centre offsets can still pass. The scoped refusal
`cpu-selected-pixel-first-surface-exceeds-exact-vertex-residual` retains the raw
projection and pixel-centre offset. CPU evidence reports
`queried-ray-exact-vertex-identity`; absent or different scope refuses. No pixel
offset enlarges the physical tolerance and no vertex ray substitutes for the
selected pixel ray. Source/GPU approval remains independent and unresolved when
unavailable; corpus-wide practical reachability has not been measured.

Paused interaction verification exercises a bounded crank turn and an actual
camera orbit, preserving before/after native pixels, camera poses and media
clocks. Camera equality permits only numerical noise (1e-9 metres, radians and
FOV degrees); a real orbit must exceed that bound and change rendered pixels.
Failed interactions retain their measured predicates and screenshots.

Declared reference images are replayed from the original MP4 and checked against
their native frame indices and pixel hashes. Frame selection uses a balanced
expression so long collections stay within FFmpeg's expression-depth limit;
this does not change the selected frames or split the decoder into retries.
Gray references use explicit round-to-nearest limited-to-full 8-bit luma,
not FFmpeg's version-dependent implicit gray conversion. The schema defines the
byte profile; unsupported source formats are refused and existing hashes stay
unchanged.

The pixel observer uses that same native Y raster for both gray identity and
NCC/LK measurements, selected by the declared pixel format rather than video ID.
Source clocks use native integer PTS with the rational stream time base, not
microsecond-rounded display timestamps at half-open cuts. Install its locked
web tooling group from the repository root. With `HARMONIC_REFERENCE_ROOT`
pointing to the unchanged original reference root, a private observation run is:

```sh
uv sync --group web
uv run --group web python web/scripts/observe-source.py \
  --source "$HARMONIC_REFERENCE_ROOT/videos/4mBuyixt22U.mp4" \
  --observations web/content/v39-source/4mBuyixt22U.observations.json.gz \
  --output web/.vite/verification-output/rocker-observed.observations.json.gz
```

Successful decoding/emission does not certify missing independent measurements
or promote unavailable source coverage to passed.

Compact selection preserves original landmark observations across nominal and
decoded-time aliases only when source frame, hashes, PTS and view layout match.
It does not interpolate source pixels or change the selected camera and input.
Exact aliases use the declared `sha256Bgr8` or `sha256Gray8` hash for their
pixel format. Formats never alias each other; sampling diagnostics list
supported formats and any unsupported source declarations.

Current authored inputs are `content/v39-source/<videoId>.observations.json.gz`;
browser outputs are `content/<videoId>.source-track.json`. Preserve source PTS,
pixels, hashes, uncertainties and landmarks. For each CAD release, recompute
native identities, world coordinates, cameras and physical constraints against
the approved geometry. Inherited pose seeds remain chosen/unobserved.
The identity-translated packets under `content/canonical-native/` and byte-exact
originals under `content/` from `bfde892a5` remain historical lineage, including
their old projection/GPU proof; they do not qualify current geometry.

From the repository root, store an authored input without reserializing JSON:

```sh
uv run --isolated --no-project python web/scripts/canonical-native-evidence.py compress-observations web/content/v39-source/<ID>.observations.json
```

The command retains the source file and writes exact-byte deterministic gzip
(level 9, `mtime=0`, no filename). Only the registered authored observation
namespace is accepted. Compression preserves numeric spelling and supplies no
geometry or fidelity qualification.

After authoring stops, regenerate in this order using the pinned source-fit
requirements for the four producers:

```sh
uv run --isolated --no-project python web/scripts/canonical-native-evidence.py generate
uv run --isolated --no-project --python 3.13 --with-requirements web/scripts/source-fit-requirements.txt python web/scripts/generate-intro-source-track.py
uv run --isolated --no-project --python 3.13 --with-requirements web/scripts/source-fit-requirements.txt python web/scripts/generate-analysis-synthesis-source-tracks.py
uv run --isolated --no-project --python 3.13 --with-requirements web/scripts/source-fit-requirements.txt python web/scripts/compact-spin.py
uv run --isolated --no-project --python 3.13 --with-requirements web/scripts/source-fit-requirements.txt python web/scripts/compact-operation-rocker.py
uv run --isolated --no-project python web/scripts/canonical-native-evidence.py generate
uv run --isolated --no-project python web/scripts/canonical-native-evidence.py check
```

The first canonical generation refreshes input seals; the final generate/check
binds the produced tracks. Canonical replay remains an identity audit.
Operation/Rocker accepts `--video jfH-NbsmvD4` or `--video 4mBuyixt22U` for
independent publication; its default prevalidates the pair before publishing
either. Analysis/Synthesis retains its independent `--video` selection.

One-ULP routing at half-open cuts is execution-only: authored source numbers
remain unchanged, and the strict same-shot 0.5-second source-exposure requirement
still applies. Nine actual independently decoded frames fill genuinely missing
Operation fade exposures while preserving existing samples and landmarks.
Inherited camera/mechanism guesses remain chosen/unobserved. Complete playable
approximate tracks do not imply a source-fidelity pass. Fresh rendered reports
must distinguish measured failures, unavailable coverage and unmeasured stages;
there is no acceptance-attempt quota.

The [derivative manifest](content/canonical-native/manifest.json) records each
derivative and original SHA-256, mapping revision and digest, preserved numeric
tokens, and sealed historical-code snapshots. Those code seals establish
original lineage only. They do not qualify the current renderer or CAD.
Analysis's native forward-smoke, visible-crank winding proof and extraction-lineage
code seals verify their original historical producers, not today's native math.
Missing, unreadable or modified historical snapshots reject with `ValueError`.
Synthesis's historical automatic-motion `generationDependencies` now read every
non-content producer/math input only from its exact sealed historical-code
archive. Native-data text comes from those same original archived bytes, never
the live current tuple. The content evidence dependency remains the original
pinned packet at the intended evidence root. The cam-rod
`sceneCurrentSourceSha256` retains its original field name and digest but checks
the corresponding sealed historical scene archive. Missing or modified archives
refuse even when matching bytes exist at nominal live source paths; there is no
live-file or replay-root fallback.

The ordinary current producer remains fresh-only and separately checks its live
authority and observation byte seals. Whole historical receipt revalidation
uses the real archive route without overriding byte/text reads. It preserves
original packet and receipt seals and cannot approve current scene, math,
model, GPU or source fidelity. Historical code, original packets and geometry
remain exact-byte evidence.
Original private capture paths and observation hashes remain provenance links,
not regeneration dependencies; no source video or screenshots are included.
Capture-bound renderer and model hashes remain strict. Current-renderer
recapture and source requalification against the approved v39 native geometry
are required before claiming current-model source fidelity.
Lossless delivery optimization keeps the native raw hash authoritative; it does
not recalibrate observations or establish geometry/source fidelity acceptance.

`npm --prefix web run test:source` runs the source-generation boundary tests
through uv in an isolated Python environment. The suite covers exact-exposure
identity, conflicting landmarks and invalid presentation declarations.

Legacy full-part visibility, finite-line, contour and raster-bound diagnostics
remain historical evidence, not an exhaustive queue that must finish before
source-following animation can be demonstrated. Preserve their real bug fixes
when using those measurement paths. See [`DESIGN.md`](DESIGN.md) for the current
track, coverage and verification contract.

Reports and local screenshots go to `web/.vite/verification-output/` and are
ignored. `HARMONIC_CHROME` selects the Chromium executable; `HARMONIC_HEADLESS=1`
is available for automation. External-media restrictions are failures, not skips.

## Deployment

Cloudflare Workers Builds uses native Git integration (not a GitHub deployment
token or OIDC). Both Workers use repository root **`web`**, install with
`npm ci`, and build with **`npm run build:deploy`**. Wrangler is pinned to
**4.148.0** in the lockfile. The build produces **`web/dist/`** at base path `/`,
including `/deployment.json` with the exact `WORKERS_CI_COMMIT_SHA` and
`WORKERS_CI_BRANCH`. Local builds fall back to the current Git commit/branch;
detached checkouts must supply both native-build variables.
The npm `prebuild:deploy` lifecycle runs `npm run test:deployments` first, so the
deployment identity, reporting and cleanup regression tests gate native builds.

| Deployment | Account name / workers.dev subdomain | Account ID | Worker | Native deploy command |
|---|---|---|---|---|
| Production (`main` only) | `harmonicanalyzer-com-prod` | `6b2522c874d4613dc2bf47bd2ce521a2` | `harmonicanalyzer-com-prod` | `npm run deploy` |
| PPE (branch previews, all PR base branches) | `harmonicanalyzer-com-ppe` | `c8769c20b85cd2857afe22ef2f9a0a21` | `harmonicanalyzer-com-ppe` | `npm run deploy:preview` |

Worker service names match their account names and account subdomains; account
IDs are unchanged. Production's primary URL is `https://harmonicanalyzer.com`.
The companion origin remains
`https://harmonicanalyzer-com-prod.harmonicanalyzer-com-prod.workers.dev`.
The PPE service origin is
`https://harmonicanalyzer-com-ppe.harmonicanalyzer-com-ppe.workers.dev`;
branch Preview API URLs use
`https://<preview-slug>-harmonicanalyzer-com-ppe.harmonicanalyzer-com-ppe.workers.dev`.
GitHub's `production` and `web-preview` environment variables
`CLOUDFLARE_WORKERS_SUBDOMAIN` must match the respective account subdomains above.

Production `wrangler.jsonc` declares the apex as a Workers Custom Domain so
future deployments retain the binding. Worker logs, invocation logs and traces
are enabled with 100% head sampling. Static assets served without invoking the
Worker do not produce Worker invocation telemetry.

Cloudflare Web Analytics is enabled for `harmonicanalyzer.com` in the production
account, with automatic edge injection and full RUM (`lite: false`). Its beacon
collects page visits and Web Vitals; no duplicate script is installed in the app,
and PPE/local pages are not included. Manage this zone-owned setting in
Cloudflare **Web Analytics**, not Wrangler. Verify the injected
`static.cloudflareinsights.com/beacon.min.js` and successful `/cdn-cgi/rum`
requests in a browser; dashboard aggregates can lag collection.

PPE uses `wrangler preview --config wrangler.ppe.jsonc --name "$WORKERS_CI_BRANCH"`
for both its default branch and non-production branch build command. It never
publishes the PPE production Worker with `wrangler deploy`. Production
non-production branch builds must be **disabled in the dashboard**.
Native Git build watch paths use Cloudflare's `web/*` wildcard on both PPE
triggers (main and non-main) and production. GitHub workflow path filters use
`web/**`; these are separate matching systems. GitHub environment reporting and
PPE preview cleanup do not perform deployments. The sole GitHub cleanup token
belongs to the PPE environment/account, never the production account.

Native previews cover **same-repository PR branches**, including drafts and PRs
targeting any base branch, when `web/**` changes. Valid unsupported fork PRs are
**explicitly skipped**, not failed or represented as deployed; the job skips
before credentials, checkout or API calls. Malformed event payloads still fail.
Untrusted fork code never enters a credentialed native build. GitHub's PPE
environment records the actual Cloudflare Preview API URL, not a guessed branch
slug, and normally reports success only after `/deployment.json` matches the
exact PR head SHA and raw branch name. If native watch paths skipped a
non-`web/**` push, an older manifest commit is accepted only when the raw branch
matches and GitHub's root `web` subtree object SHA is identical for that commit
and the requested head. The successful deployment records the **actual manifest
SHA**, with `requestedSha` and `identityProof: "matching-web-tree"` in its
payload; it never mislabels old bytes as the new head. Changed-web mismatches
still fail within the bounded wait. An arbitrary HTTP 200 is not deployment
proof. Production
reporting uses the same exact-commit or proven web-tree-equivalence rule;
the standalone `wait` helper remains exact-SHA-only.
Native deployment is **push-only**: opening or reopening a PR does not trigger
a new Cloudflare build. After a closed PR's Preview has been deleted, reopening
that PR requires a **new push touching `web/`** to recreate it. A reopened PR
with no Preview fails reporting immediately with that instruction. A newly
opened PR still allows the normal bounded 20-minute native startup wait before
reporting a native-build-log/new-web-push diagnostic. Neither path attempts a
build through an additional PPE build-control token.

The PPE cleanup credential is used only to read Preview metadata and delete PPE
Previews. The accepted cleanup contract is **branch-only**: PR closure deletes
the closed branch's Preview resource and branch URL, releases its Preview quota,
and inactivates the GitHub deployment record, unless another open PR shares
that branch. **Immutable deployment URLs deliberately remain public** under the
accepted contract because of Cloudflare's beta behavior documented in
[issue 15945](https://github.com/cloudflare/workers-sdk/issues/15945). A live
cleanup probe confirmed that the Preview resource disappeared and the branch
URL returned 404 while an older immutable deployment URL still served its
deployed bytes. Branch cleanup does not promise full public-URL revocation.
Closed-PR cleanup issues the delete immediately, without the orphan grace
period; branch-URL removal then propagates asynchronously through Cloudflare.
A successful delete is not an instant data-plane 404: a second disposable probe
initially returned 200 after deletion and subsequently returned 404 within the
bounded propagation observation.

Cleanup retries still inactivate matching GitHub deployment records when the
Preview resource and Git branch are already gone. The helper decodes GitHub's
string-wrapped GraphQL deployment payload to recover the recorded branch, and
uses paginated bulk `latestStatus` data to skip already-inactive records without
a separate status-history request for every deployment.
Unreadable payloads are left unchanged without inferring ownership from their
Git refs. Valid later records are still cleaned up; afterward the run fails
with an aggregate error naming the unreadable deployment IDs. GitHub API and
status-write failures propagate immediately rather than being treated as
unreadable payloads.

An hourly reconciler catches late builds and orphaned Preview resources. It
preserves new Previews without a PR for their first **30 minutes**, allowing a
branch push to precede PR creation; otherwise orphan **Preview-resource**
cleanup occurs within **90 minutes of Preview creation**, excluding scheduler
delays. This bound does not imply immutable deployment URL revocation. Missing or
malformed API `created_on` timestamps stop reconciliation instead of risking
premature deletion. Open PR branches are preserved. The deployment lifecycle
helper can also be used manually:

```sh
node web/scripts/cloudflare-deployments.mjs preview
node web/scripts/cloudflare-deployments.mjs production
node web/scripts/cloudflare-deployments.mjs list
node web/scripts/cloudflare-deployments.mjs reconcile
node web/scripts/cloudflare-deployments.mjs cleanup 'raw/branch-name'
node web/scripts/cloudflare-deployments.mjs wait URL FULL_COMMIT_SHA [BRANCH [TIMEOUT_SECONDS]]
```

`wait` accepts an application base URL with or without a trailing slash and
preserves any non-root base path when resolving `deployment.json`.

`list`, `reconcile`, and cleanup require `CLOUDFLARE_CLEANUP_API_TOKEN` plus
the fixed PPE `CLOUDFLARE_ACCOUNT_ID`, `CLOUDFLARE_WORKER_NAME`, and
`CLOUDFLARE_WORKERS_SUBDOMAIN` environment values. `cleanup` and `reconcile`
also require `GH_TOKEN` and `GITHUB_REPOSITORY` to protect open PR branches.
The low-level `delete RAW_BRANCH` command deliberately bypasses that open-PR
protection; reserve it for intentional preview-deletion smoke checks.

The Wrangler files explicitly pin account and Worker identity. Both use the
static asset binding and a lossless asset streaming Worker, with no storage,
secrets, unrelated bindings or scheduled triggers. Production also declares its
apex custom domain and observability settings; PPE has no custom domains.
`keep_vars` preserves dashboard variables.
PPE explicitly has a `previews` block to enable noninteractive deployments
without copying production resource settings. It enables Preview console logs
for structured `deployment-asset-stream-abort` diagnostics only; automatic
invocation logs are disabled. Wrangler 4.148.0 retains `assets` (including
`ASSETS` and `run_worker_first`) at the top level, not under `previews`.

The approved v39 optimized model is **41,072,516 bytes**, exceeding the
[25 MiB per-file Workers Assets limit](https://developers.cloudflare.com/workers/platform/limits/#static-assets)
on both Free and Paid plans. `build:deploy` therefore downloads the immutable
[SHA-named v39 optimized release asset](https://github.com/pedropaulovc/harmonic-analyzer/releases/download/v39/ha-harmonic-analyzer-941b6193698091781f133642bdc2a7411a18c2cfcb5252646a79b9bd57c6a805.glb),
checks its SHA-256 and exact length against `content/model-representation.json`,
and caches it under ignored `.vite/deployment-model/`. GitHub is a **build-time
input only**: the deployed application makes no model requests to GitHub.
Missing or wrong bytes fail the build. It neither imports a different CAD model
nor regenerates tracked provenance/native metadata.

After Vite builds, every runtime file larger than 25 MiB (including the model
and large source-track JavaScript modules) gets a lossless gzip representation
and an identity fallback. Each representation is split into ordered **24 MiB**
pieces under `dist/deployment-assets/`. The generated, ignored
`.vite/deployment-assets.json` records original URLs, decoded lengths and
SHA-256 values, plus each representation's encoded length, digest and ordered
pieces. The build verifies the pieces, reconstructed representations and exact
decoded original bytes before deployment. Geometry and source datasets stay
unchanged.

For original chunked-asset URLs, the Worker selects gzip or identity from
`request.cf.clientAcceptEncoding`, not Cloudflare's normalized edge header.
Missing original Cloudflare metadata selects identity; non-Cloudflare requests
use their raw header.

**Native Preview limitation:** measured Cloudflare metadata drops `q` values and
wildcard entries before the Worker. Worker-first routing did not restore them.
The parser respects qualities and returns 406 when both codings are refused
only where raw/preserved metadata is available; it cannot recover preferences
discarded by the platform. This is not a deployed quality-negotiation guarantee.

GET/HEAD responses include the
selected representation's length and ETag, `Vary: Accept-Encoding`, and
`Content-Encoding: gzip` when selected. It sequentially streams immutable pieces
through a fixed-length stream, without runtime compression or a full-file buffer.
Initial missing chunks return 502; later missing/short chunks error the response
stream rather than silently completing a truncated 200. The model loader verifies the
original compiled SHA-256 and length before parsing. Ordinary files pass through
to `ASSETS` unchanged, including their native conditional-request behavior.
Each immutable `ASSETS` piece is requested with `Accept-Encoding: identity` and
must return 200 with a body. If a Content-Length header is visible it must match
the manifest, but the native binding can omit that header even though its public
HTTP endpoint supplies it. Piece length and SHA-256 checks, plus exact ordered
whole-file SHA reconstruction, are mandatory **producer/predeploy** checks.
Runtime bodies pipe directly into one native `FixedLengthStream`, which enforces
the **actual total byte length** without per-packet JavaScript processing or
materialized arrays. This relies on Cloudflare's immutable `ASSETS` producer for
individual pieces; there is no separate per-piece runtime byte/SHA scan.
The browser still verifies the complete model SHA before parsing.
Abort diagnostics identify the original URL, active piece path, and error
without body bytes. Header/status refusals include actual response status,
visible length, encoding and expected length.
Chunked routes also honor strong/weak `If-None-Match` and `*` with a 304 before
fetching any pieces, so cache revalidation does not redownload the full asset.
Reconstructed routes retain `Cache-Control: no-transform` so Cloudflare does
not recompress either the precompressed gzip or identity response. A native headed-browser control found
that default `Content-Encoding: zstd` failed partway through the 45,568,082-byte
playback module, while an identity-encoding override completed the exact full
module with HTTP/3 unchanged. The response's Content-Length had been removed
under zstd, so this was not evidence of an explicit length-header mismatch.
The transport uses Cloudflare's
[documented no-transform directive](https://developers.cloudflare.com/speed/optimization/content/compression/#content-length-header-handling),
not an HTTP/3-disabled client fallback. The no-transform-only native deployment
still failed concurrent model/module loads, with Cloudflare invocation analytics
reporting `exceededResources`; this outcome does not identify CPU versus memory.
The transport therefore avoids per-buffer JavaScript processing through native
stream piping. Public native-browser verification is required before claiming
the deployed resource fix verified.
Both configurations explicitly use `run_worker_first: false`, Cloudflare's
asset-first default. Ordinary uploaded files (including the transport pieces)
bypass the Worker; these static requests are
[free and unlimited](https://developers.cloudflare.com/workers/static-assets/billing-and-limitations/).
The producer deletes oversized originals only after writing all their pieces,
so requests to those original missing URLs fall through to the Worker and use
the manifest transport, regardless of their directory. Keep
`not_found_handling` at its default `none`: no SPA or custom 404 asset fallback
is configured to swallow these missing-original requests.
Reconstructed original requests still invoke the Worker and retain its
[plan limits](https://developers.cloudflare.com/workers/platform/limits/#daily-requests),
including **100,000 requests/day on Workers Free**; they are not unlimited
static delivery. No visitor/cost estimate is implied by the routing change.
No R2 storage or runtime external origin is required.
Original reference footage is local opt-in verification data, not published:
deployment builds reject a `public/reference-media/` directory.

From a clean clone, the equivalent commands are:

```sh
npm --prefix web ci
npm --prefix web run build:deploy
# Authenticated local use only; native Builds supplies Cloudflare credentials.
npm --prefix web run deploy          # main -> production
npm --prefix web run deploy:preview  # actual branch -> PPE preview
```

Plain `npm --prefix web run build` remains the local static Vite build with
default base `/harmonic-analyzer/`; it is not the native deployment build.
Deployment never publishes the raw CAD export or private source cache.
Exact geometry sharing reduces duplicate buffers; Meshopt reduces transfer
bytes, not the instance-expanded triangle count. No frame-rate improvement is
established. Fidelity verification still uses all twenty channels and the full
geometry; it must not substitute reduced geometry.

### Runtime performance checks

Normal source polling reuses a completed draw only when the media clock,
presented native exposure, source/model identity and draw revision are unchanged.
Pending paint, seeks and explicit diagnostic publications still draw. HUD fields
are written only when their displayed values change. The manual crank retains
elapsed-time motion; idle exploration already renders on demand.

Spring meshes use independent live bounding spheres that enclose their current
shader-deformed vertices, including translated hooks and transition curves.
Only springs outside the camera frustum skip submission. Geometry, materials,
names and native diagnostic ownership are unchanged; full-machine views may
save no draws.

`scripts/measure-performance.js` records three cold-cache navigations, resource
bytes and five-second idle/manual-crank WebGL draw windows. Its draw wrappers add
CPU overhead. `scripts/measure-cpu.js` measures idle, manual and actual
source-following CPU windows without those wrappers. Run each in a fresh native
Windows Chrome session, from the repository root in Windows PowerShell:

```powershell
playwright-cli -s=performance open http://localhost:4178/harmonic-analyzer/ --browser=chrome --headed
playwright-cli -s=performance run-code --filename=web/scripts/measure-performance.js
playwright-cli -s=performance close
playwright-cli -s=cpu open http://localhost:4178/harmonic-analyzer/ --browser=chrome --headed
playwright-cli -s=cpu run-code --filename=web/scripts/measure-cpu.js
playwright-cli -s=cpu close
```

Run `npm --prefix web run build` and `npm --prefix web run preview -- --host
0.0.0.0 --port 4178` first. A plain build needs the approved model staged through
the normal model workflow; `build:deploy` acquires it automatically. Compare the
same browser, viewport, pixel ratio and throttling conditions. Draw calls measure
submission work, not GPU elapsed time. Vite's local compression is not evidence
of Worker encoding negotiation: check actual hosted response headers and
transferred bytes separately. Localhost timings establish neither hosted load
time nor real-user Core Web Vitals.
Both probes disable CLI focus emulation, activate the native browser tab, retain
blur/hidden events throughout each sample, and validate window/mode endpoints.
Keep the window unobscured: Windows Chrome can throttle an occluded window to
1 Hz. Discard interrupted samples; playback status is checked at endpoints.

The 2026-10-08 native Preview delivery check retained the approved decoded
SHA-256 while reducing the oversized responses below. These are encoded body
bytes, not page-load or FPS improvements:

| Asset | Identity bytes | Gzip bytes | Reduction |
|---|---:|---:|---:|
| Approved Meshopt GLB | 41,072,516 | 31,547,135 | 23.2% |
| Intro source track | 45,568,082 | 1,689,190 | 96.3% |

The approach follows the measurement-first
[web-quality performance skill](https://github.com/addyosmani/web-quality-skills)
and [Three agent skills](https://github.com/emalorenzo/three-agent-skills).

`build:deploy` runs `test:performance` after acquiring the pinned model, before
Vite and publication. To run it separately, use `npm --prefix web run
test:performance` with the cached model, or set `SPRING_MODEL_PATH` to its exact
approved bytes. Tests cover polling/HUD transitions, encoded delivery and every
actual native spring vertex at catalog limits and source override spans.

The source-v37 measurements and verification results below are preserved from
that snapshot. Use the [subsystem identity guide](../cad/docs/subsystem-identities.md)
for current CAD identities.

The current source-v37 import produced the same result in two runs:

| Representation | Bytes |
|---|---:|
| Raw native export | 222,903,724 |
| Exact deduplication | 61,672,576 |
| Meshopt delivery asset | 38,975,844 |

This is an 82.5145% reduction in delivered model bytes. All 429 source nodes and
433 drawable instances are preserved; triangle count is unchanged. Native
mechanical metadata is unchanged. These measurements establish lossless asset
delivery, not geometry/source fidelity acceptance or a frame-rate improvement.

A headed Chromium smoke matched the optimized download hash and byte count to
the compiled raw association, with 435 runtime drawables and no missing bindings.
All twenty rocker GPU raster records matched the raw baseline bit-for-bit;
all twenty spring lengths changed independently. Three continuous original-MP4
Analysis/Synthesis clips had no stall, pause or error events; the maximum
video/completed-draw delta was 54.341 ms after an explicit initial 0.1-second
startup exclusion. This is not an FPS measurement or a new source calibration.
Source-regression replay uses explicit historical source fixtures; production
cam-rod and automatic-motion current-code guards still refuse stale evidence.
No historical receipt is rehashed or accepted as fresh calibration.
The 33 model tests pass, including real-exporter acceptance of compatible future
geometry and rejection of unsupported ratio, pitch, feed-sign and spring-profile
changes before publication. A current raw reimport reproduced the same optimized
hash and size.

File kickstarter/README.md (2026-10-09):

# Kickstarter: funding the book

Current Kickstarter workstream status and sequencing live in the
[Harmonic Analyzer project](https://github.com/users/pedropaulovc/projects/1).
All campaign copy in this directory remains draft until it is published.

The campaign funds one thing. The time and material to machine a Michelson
harmonic analyzer from scratch, and to write down every operation so that a
hobby machinist with a lathe and a mill can build one too.

| what | where |
|---|---|
| Who this is for, and the one-sentence pitch | [`campaign/positioning.md`](campaign/positioning.md) |
| The campaign page, section by section | [`campaign/page-outline.md`](campaign/page-outline.md) |
| How progress becomes blog, video, email and outreach | [`campaign/content-strategy.md`](campaign/content-strategy.md) |
| Reward tiers and what each one costs to fulfil | [`rewards/tiers.md`](rewards/tiers.md) |
| Funding goal, built up from real line items | [`campaign/budget.md`](campaign/budget.md) |
| Risks & Challenges (Kickstarter requires this section) | [`campaign/risks.md`](campaign/risks.md) |
| Pre-launch, launch and fulfilment schedule | [`campaign/timeline.md`](campaign/timeline.md) |
| Every image, video and graphic the page needs | [`assets/README.md`](assets/README.md) |
| Questions backers will ask | [`campaign/faq.md`](campaign/faq.md) |

## The honest position

A campaign that looks finished before it launches is a much easier sell than a
promise. (Widely repeated as campaign advice. Find a citable source before this
line goes anywhere public.) What this project has going for it is that a large,
verifiable chunk of the work is already done and already public:

- 149 registered CAD part families, generated from Python scripts, with a build
  pipeline that gates every assembly on DOF, interference and mass properties.
  See the [subsystem identity guide](../cad/docs/subsystem-identities.md) for the
  inventory and the root [README](../README.md) for the CAD model.
- A photo-vs-CAD comparison gallery scoring the model against Hammack, Kranz and
  Carpenter's photographs of the surviving University of Illinois machine.
- A per-part manufacturability pass
  ([`cad/docs/machining-dfm.md`](../cad/docs/machining-dfm.md)) that already names the
  three parts carrying the whole risk.

The campaign should lead with that evidence rather than with a promise.

## Hard rules for this directory

1. No pricing, quote, or reward tier is real until it is sourced. Anything
   speculative is marked `TBD` or `[EST]`. Do not let an estimate quietly become
   a commitment on the campaign page, because Kickstarter tiers cannot be edited
   downward after launch.
2. Do not promise a physical machine as a reward. Building one analyzer is the
   project. Building twenty is a manufacturing business. See
   [`rewards/tiers.md`](rewards/tiers.md) for what is and isn't shippable.
3. Respect the source material's copyright. *Albert Michelson's Harmonic
   Analyzer* (Hammack, Kranz & Carpenter, 2014) is free to view and share for
   non-commercial purposes. This book is commercial. It may cite, reference and
   build on that work. It may not reproduce their photographs or text. Original
   renders, original photographs, original prose only. See
   [`campaign/risks.md`](campaign/risks.md) §IP.
4. The machine itself is not patented and never was. Michelson's design is
   comfortably public domain, so the constraint is the 2014 book, not the 1898
   machine.

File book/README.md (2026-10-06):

# The book

**_Albert Michelson's Harmonic Analyzer: A Project for Hobby Machinists_**.
Step-by-step machining instructions for building a working 20-element harmonic
analyzer on a manual mill and lathe.

The book is the main machining and publication deliverable. The
[CAD model](../cad) supplies the geometry, the
[logbook](../logbook/README.md) supplies the process, the
[website](../web/README.md) shows readers what they are building, and the
[Kickstarter](../kickstarter/README.md) funds the work. The
[AI story](../ai-story/README.md) is a separate, first-class workstream.

Part tables and CAD source links use the canonical subsystem-prefixed identities.
The [subsystem identity guide](../cad/docs/subsystem-identities.md) lists drawing
numbers and the old-to-current lookup for historical bench records.

## Work status

Current Book workstream status and sequencing live in the
[Harmonic Analyzer project](https://github.com/users/pedropaulovc/projects/1).
Each chapter's `status:` frontmatter is authoritative for its own maturity.
[`outline.md`](outline.md) owns scope and order, not status.

## Build it

Authored in [Quarto](https://quarto.org): Markdown in, print PDF plus HTML plus
EPUB out.

```powershell
# one-off: install Quarto (https://quarto.org/docs/get-started/) and a LaTeX engine
quarto install tinytex

# refresh figures from the CAD build, then render
uv run python book/scripts/collect_figures.py
quarto render book                 # all formats -> book/_book/
quarto render book --to pdf        # just the print PDF
quarto preview book                # live-reload HTML while writing
```

`collect_figures.py` copies renders and drawing sheets out of `cad/out/` into
`book/figures/generated/` (gitignored) and writes a manifest. A chapter can then
reference a stable path while the render itself stays a build artefact. It also
deletes figures the build no longer produces, so a renamed render cannot leave a
stale copy behind for a chapter to keep pointing at. Run `doit build` first if
`cad/out/` is empty or stale.

## Layout

```
book/
  _quarto.yml          project + book config (chapter order lives here)
  index.qmd            title page / front matter
  outline.md           the plan: every chapter, scope and reading order
  front/               preface, how to use this book, safety
  chapters/            the book, in reading order
  appendices/          BOM, drawing index, cutter tables, fits, suppliers
  _templates/          skeletons for a new part chapter / operation
  figures/
    generated/         copied from cad/out by scripts/collect_figures.py (gitignored)
    hand/              hand-made diagrams, tracked
  scripts/             figure collection and other build helpers
  references.bib       citations
```

## The rule that matters

Chapters may be drafted from CAD and cited references before the corresponding
shop work. A draft must not present an unperformed feed, setup or measurement as
observed fact; it marks that gap `TODO(cut it first)`.

Real feeds, speeds, setups, measurements and mistakes come from
[`logbook/`](../logbook/README.md). A chapter becomes `verified` only after the
part has been made by following the text.

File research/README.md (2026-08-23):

I want to recreate Albert Michelson's Harmonic Analyzer. I want to recreate it in as close fidelity as possible. I don't have any prior experience with machining, metal manufacturing or 3D CAD but I have years of experience as a software engineer.

The analyzer is described in details in the PDF book and YouTube videos transcripts included in the documents. It might also be possible to access an existing replica of the analyzer but this should only be used as a last effort since it requires air travel and convincing an university to allow me to have access to it.

Use terse, technical language whenever possible. Ask for clarifications whenever there's ambiguity. Highlight any assumptions you make along the way.

This project will be shared on GitHub as a didactic but advanced way to use large language models for learning.

> **Historical initial plan.** The phases and dates below are preserved as
> provenance. They are not current status or schedule. Current work and
> sequencing live in the
> [Harmonic Analyzer project](https://github.com/users/pedropaulovc/projects/1).

# Study and Implementation Plan: Recreating Albert Michelson's Harmonic Analyzer

## Phase 1: Research and Documentation (2 weeks)
	* Review provided PDF and video transcripts thoroughly.
	* Document the mechanical principles, gear ratios, and mechanisms (e.g., cone gear sets, cylinder gear sets, rocker arms).
	* Create a detailed component list and identify precise manufacturing methods.

## Phase 2: Preliminary Design (3 weeks)
	* Select appropriate CAD software (e.g., SOLIDWORKS, Autodesk Inventor).
	* Initial CAD modeling of critical components (gears, levers, springs, cams).
	* Identify potential suppliers for specialized parts (springs, precision gears).

## Phase 3: Detailed Design and CAD Finalization (4 weeks)
	* Complete CAD models with high fidelity, including annotations and tolerances.
	* Conduct simulations to validate mechanical interactions and performance.
	* Prepare manufacturing blueprints and assembly instructions.

## Phase 4: Manufacturing and Procurement (6 weeks)
	* Engage professional machining or additive manufacturing (metal 3D printing) vendors.
	* Source off-the-shelf components and materials.
	* Supervise quality control checks of critical parts (gears, cams, rocker arms).

## Phase 5: Assembly and Calibration (4 weeks)
	* Assemble mechanical components following CAD models and instructions.
	* Iteratively calibrate and adjust (e.g., amplitude bars, summing levers, pen mechanism).
	* Document procedures and identify potential mechanical adjustments or improvements.

## Phase 6: Testing and Validation (3 weeks)
	* Conduct thorough testing to replicate documented Fourier analysis and synthesis results.
	* Adjust and refine based on observed performance and historical comparisons.
	* Document performance metrics and troubleshooting methods.

## Phase 7: Documentation and Publication (2 weeks)
	* Prepare comprehensive project documentation including assembly guides, CAD files, and calibration instructions.
	* Publish findings and resources on GitHub for educational and collaborative purposes.
	* Estimated Total Duration: 24 weeks (6 months)
	* Regular milestones and progress reviews every two weeks to ensure project alignment and quality assurance.

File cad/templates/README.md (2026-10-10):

# Harmonic-analyzer SolidWorks templates

The project-owned SolidWorks templates, all **created manually in SolidWorks**
(not generated — the old `create_drawing_standards.py` generator and the
`asme-b-book.*` assets it produced are gone). Edit them only in SolidWorks,
then rebuild/re-render and visually inspect before committing the changed
binary.

## harmonic-analyzer.PRTDOT — part template

The default part template every `part:*` build instantiates.
`_common._pin_default_part_template` points the seat's default-part-template
preference at it on every build connect (read-back verified, raises on
failure), so a build never silently runs on a drifted seat template. It must
carry the DimXpert block-tolerance document properties that are GET-ONLY over
COM on R2026x — notably the **angular tolerance ±1°** and the 2/3-decimal
linear precisions (`cad/config/title_block.yaml` is the source of truth;
`_common.apply_block_tolerances` stamps the settable ones and RAISES if the
get-only ones drift from the config). The template is a `file_dep` of every
part task (`dodo.PART_TEMPLATE`), so editing it rebuilds all parts and busts
their cache keys.

## Drawing templates

Manufacturing drawings select one of two ASME B templates:

- `harmonic-analyzer-landscape.DRWDOT`: 431.8 × 279.4 mm
- `harmonic-analyzer-portrait.DRWDOT`: 279.4 × 431.8 mm

Both templates contain their border and zone geometry, title block, tolerance
block, and third-angle projection symbol. The sheet formats are embedded, so
there is no separate `.slddrt`. `_drawing_registry.DRAWING_TEMPLATES` owns each
template's path, physical dimensions, raster dimensions, and title-block
keep-out. Every `DrawingSpec` selects a `DrawingLayout` explicitly. The current
production fleet uses landscape; changing a row to portrait switches that
drawing's template and cache dependency together.

Per-drawing setup sets the sheet scale
(`_drawing_common.new_project_drawing`). `_drawing_common.finalize_drawing`
links each sheet's custom-property view to its first drawing view and enforces
the standard isometric projection as high-quality Shaded With Edges.

### Line weights

Both drawing templates set Document Properties > Line Thickness to
**Thin 0.13 mm** and **Normal 0.18 mm**. Thick through Thick(6) keep the
SolidWorks defaults (0.35 to 2.0 mm). Line Font maps visible edges to Normal
and hidden edges, tangent edges, cosmetic threads, and hatch to Thin. The border
uses Thick(2), 0.5 mm.

The SolidWorks defaults of 0.18 mm and 0.25 mm filled dense assembly views at
1:3 with ink. Examples include the cone gear teeth and screw threads on
`drive-train-assembly` sheet 1. The lighter pair keeps the 1.4:1 contrast
between visible and thin lines. ISO 128 lists 0.13 mm as its thinnest line
width. To check weights in an exported PDF, read the stroke widths from its
drawing operators with PyMuPDF `page.get_drawings()`, and multiply by
25.4/72 to get millimetres.

`third-angle-projection.SLDBLK` is the projection-symbol block embedded in both
templates and remains the editable source for future template work.

The layout audit reads the title-block keep-out from `DRAWING_TEMPLATES`. Its
measured `(left, top)` bounds are `(0.216, 0.066)` m for landscape and
`(0.0636, 0.066)` m for portrait. Re-measure and update the matching registry
entry if either block moves or grows.

### Title block

Left side, top to bottom: the general-tolerance block (**UNLESS OTHERWISE
SPECIFIED**; `.XX` / `.XXX` / angular / surface finish, linked to the source
part's `TOL_LIN_XX` / `TOL_LIN_XXX` / `TOL_ANG` / `TOL_SURFACE` custom
properties from `cad/config/title_block.yaml`); the edge-break note; FINISH;
MATERIAL; the ASME Y14.5-2018 interpretation note; DO NOT SCALE DRAWING; and
the third-angle projection symbol. Right side: project title; PART name; DWG.
NO. (`Number`, the MHA-<subsystem>-### registry id (assembly 000; parts 001 onward)); REV (the release tag); scale; UNIT;
copyright + CC BY-SA mark. The source part supplies the linked `$PRPSHEET`
fields. `_common.part_properties` stamps `Number`, `Revision`, `Title`, and
the `TOL_*` set. `_drawing_marks.apply_drawing_properties` stamps `Drawn By`
and `Revision Description`. Consolidating these stamping paths is tracked in
issue #249.

`finalize_drawing` requires the `TOL_*` set on the linked model, so a stale
source part fails before it can save blank tolerance cells.

The cone-pivot-post drawing also checks the linked Finish note's native extent
against the landscape template's cell rules. In the exported sheet, those rules
are at x = 215.900 / 308.328 mm and y = 33.584 / 44.485 mm, measured from the
lower-left sheet origin. Its check rounds these boundaries inward, not outward.
The linked value starts at about x = 217.8 mm; 218 mm is not the cell's left
rule. When editing this title block, remeasure all four boundaries and update
`draw_dt_cone_pivot_post._FINISH_CELL` with its offline containment cases; do
not move the correctly placed note merely to satisfy an obsolete inset.

The UNIT cell links `$PRP:"UnitOfMeasure"`, SolidWorks' drawing-document unit
property. SolidWorks updates it when the document unit system changes through
the status-bar unit picker: MMGS displays `mm`, and IPS displays `in`. The
pipeline configures dimensions in millimeters today. No custom UNIT property
is stamped.

### The "For Personal Use Only" watermark

Sheets rendered on a **SolidWorks Maker / Student** seat carry a non-removable
`SOLIDWORKS Maker Product. For Personal Use Only.` watermark — it is imposed by
the licence, not by this template, and there is no API to suppress it. It is
expected on every drawing produced on a Maker seat and is not a defect in the
standard. A commercial seat would render without it.

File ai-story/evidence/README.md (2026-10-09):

# Evidence

Where the receipts are, and how to pull them. **Nothing goes in a draft that
can't be sourced from one of these.**

## In-repo sources

| source | what it proves | how to read it |
|---|---|---|
| `git log` | what changed, when, and why — commit messages here carry context first, then the change, then verification | `git log --format='%h %ad %s' --date=short` |
| `memory/` | 130+ findings, mostly bugs that cost real time | `memory/MEMORY.md` is the index |
| `AGENTS.md` | design decisions **with their history**: several sections end in a "(History: this replaced X — see memory/Y)" note | read the parenthetical asides; that's where the reversals are |
| `cad/docs/` | the engineering assessments: assumptions, known limitations, DFM, tolerances | `cad/docs/known-limitations.md` is the most honest file in the repo |
| `cad/out/reports/telemetry/` | real span durations and log records per build | `traces.jsonl` / `logs.jsonl`, one OTel record per line |
| `cad/out/reports/cache.jsonl` | every cache hit/miss/store, with keys | append-only event log |
| `memory/usage.jsonl` | token/cost accounting | the only defensible source for cost claims |
| `cad/comparisons/` | how close the model got to the photographs, over time | `scores.json` is a regression trend, comparable within one render engine |

## GitHub sources

```bash
# every merged PR, oldest first
gh pr list --state merged --limit 1000 --json number,title,mergedAt,additions,deletions \
  --jq 'sort_by(.mergedAt)[] | "\(.number)\t\(.mergedAt[:10])\t+\(.additions)/-\(.deletions)\t\(.title)"'

# review comments on one PR (what automated review actually caught)
gh pr view <N> --json reviews,comments

# releases: what shipped, and when
gh release list --limit 100
```

## Useful queries

```bash
# reversals: mechanisms that were built and then removed
git log --format='%h %s' | rg -i 'revert|remove|retire|replace|kill|drop'

# memory files that record a wrong claim
rg -l -i 'was wrong|turned out|actually|does not|myth|folklore' memory/

# the slowest operations on record (calibrates every perf claim).
# NOTE: records are unordered, so they must be SORTED by duration — `head` on
# the raw file just gives you the first spans written, not the slowest ones.
# Timestamps are ISO-8601 strings with a fractional part, and jq's
# fromdateiso8601 rejects the fraction, so truncate to whole seconds (fine for
# ranking slow ops; use the raw strings if you need sub-second precision).
jq -r '[.name, ((.end_time[0:19]+"Z"|fromdateiso8601)
              - (.start_time[0:19]+"Z"|fromdateiso8601))] | @tsv' \
  cad/out/reports/telemetry/traces.jsonl | sort -k2 -gr | head -20

# Current registered inventory: 149 part families and 8 assembly identities.
# See ../../cad/docs/subsystem-identities.md; registry counts are not task counts.
# how many parts, assemblies, drawings.
# NOTE: do NOT count `build_*.py` — that file set also contains the 8 assembly
# scripts and the probe/motion-study scripts, which is how "115 parts" (wrong)
# got into an earlier draft of the README and the repo description (corrected
# across 8 files in PR #464, "repo: scaffold the five publishing deliverables").
# The build graph is authoritative for task counts, and listing needs no SolidWorks seat.
# Capture ONE listing and count that: a pipeline hides doit's exit status, so a
# run that dies after partial output still prints a plausible number.
set -euo pipefail
tasks="$(uv run python -m doit list --all)"
printf '%s\n' "$tasks" | rg -c '^part:'
printf '%s\n' "$tasks" | rg -c '^assembly:'
printf '%s\n' "$tasks" | rg -c '^drawing:'
```

## Not evidence

- **`agent-sessions-backup/` and any local transcripts.** They may contain
  paths, keys and personal detail, and they are not public. Quote only after
  the user has reviewed the specific quote.
- **Anything remembered rather than looked up.** Including by me.
- **Impressions of how much AI "did".** There is no defensible measure of that
  and reaching for one is where this genre loses its credibility.

## The counter-evidence habit

Before publishing an essay that concludes something flattering, spend a pass
looking for the record that contradicts it. Reverted commits, review comments
that caught a real bug, and memory files that begin by correcting an earlier
belief are the highest-yield places to look.

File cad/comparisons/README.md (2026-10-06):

# Photo-vs-CAD comparison pairs

Aligned pairs of real-machine reference images and SolidWorks renders, used
to iteratively tune the models toward the physical device. See
`ATTRIBUTION.md` for reference-image licensing.

## Layout

Tracked = source; **regen** = derived, gitignored and rebuilt by the tools below
(they drift as the model or the reference crops change). The `export` stage
produces the gallery from the freshly-exported STLs
(`cad/scripts/export_models.py:refresh_comparison_gallery`, best-effort: needs
Blender), and each release then **ships that snapshot inside its bundle** under
`cad/comparisons/` (`cad/scripts/cut_release.py:stage_comparisons`). The only tracked
inputs are `manifest.json`, `ATTRIBUTION.md`, this README and `tools/`; everything
else regenerates (the reference *source* photos live in the pinned `references`
submodule).

| path | tracked? | content |
|---|---|---|
| `manifest.json` | tracked | source of truth: pair id → reference, model, camera pose, legacy content-fit 2D align, tier, status |
| `ATTRIBUTION.md` | tracked | CC BY credits/licensing for the reference photos (ships in every release bundle) |
| `ref/<id>.jpg` | regen | prepared reference (cropped/rotated, ≤1600 px) — re-derived from the `references` submodule by `prepare_reference` |
| `index.html` | regen | inspection gallery (tier + text filters; drag the ref⇆cad reveal slider) — `uv run cad/comparisons/tools/gallery.py` |
| `render/<id>.jpg` | regen | raw CAD render (+ `.meta.json` staleness/engine/registration sidecar); Blender preserves concrete Pose Studio camera frames, while legacy target-less poses and SolidWorks captures are content-fit |
| `composite/<id>_cad.jpg` | regen | render registered from sidecar metadata into the reference frame (same scale/offset as the blend layer) — the slider's top image |
| `composite/<id>_blend.jpg` | regen | red-tinted render over grayscale ref — misalignment is instantly visible |
| `scores.json` | regen | pair → RMS shape score (regression trend only; compare across commits, same engine) |
| `findings/iter_NNN.json` | — | per-iteration vision findings |

## Identity boundaries

Current export and gallery inputs use canonical subsystem-prefixed stems.
Historical released bundles remain unchanged: `release_diff.py` and
`render_diff.py` pair their actual member names through the sealed schema-2
[`identity-migration-map.json`](../config/identity-migration-map.json).
Only the part stem is translated. For every non-default configuration the
exporter appends `--` plus the sanitized configuration name; the entire suffix
from the first `--` is retained, not just three-digit tooth counts. Thus
`transgear-removable--t12` pairs with `pd-transgear-removable--t12`,
`crank-handle-ferrule--installed` with
`dt-crank-handle-ferrule--installed`, and `cone-gear--t006` with
`dt-cone-gear--t006`. Generated `-stretchN` qualifiers are also retained, for
example `channel-spring-installed-stretch07` becomes
`vn-channel-spring-installed-stretch07`; an exporter `--configuration` takes
precedence over that generated suffix rule. Geometry verdicts and red highlights
remain per exact qualified mesh. The changed-part summary groups only trailing
`--t<digits>` and `-stretch<digits>` variants by base stem; other configuration
qualifiers, such as `--installed`, remain distinct summary entries.
The map is an archive-input boundary, not an old-name alias for current files
or commands.
Scene and GLB readers resolve actual historical/current bundle members.
With an explicit release tag, `pose_to_meshprobe.py` reuses an extracted
mapped cache member without contacting GitHub. Ambiguous old/current copies
are rejected rather than silently selected.

Historical curation catalogs likewise remain immutable provenance.
`seed_manifest.py` normalizes catalog components only when their
`old_underscore` identity is assigned by that same sealed map, before selecting
a studio part or the top assembly and emitting `focus`/`frame_components`.
Unknown semantic or retired unmapped labels, such as `crank_pedestal`, remain
unchanged; they require owner curation, not a guessed alias.
The normal merge retains existing tuned pairs; `--reset`
regenerates pairs using current identities. Explicit `PHOTO_FOCUS` mappings are
unchanged.

## Workflow

```powershell
# 1. curate / re-seed pairs (merge keeps hand-tuned poses)
uv run cad/comparisons/tools/dedup_stills.py
# ... vision agents write references/curation/batches/*.json ...
uv run cad/comparisons/tools/merge_catalog.py
uv run cad/comparisons/tools/extract_frames.py          # full-res video keepers
uv run cad/comparisons/tools/seed_manifest.py

# 2. render offline (no SolidWorks): refresh the STL cache once after
#     any rebuild, then Blender replays the same manifest cameras
C:\src\SolidworksMCP-python\.venv\Scripts\python.exe cad\scripts\export_models.py
uv run cad/comparisons/tools/render_offline.py [--only id,..] [--stale-only]
#    parts render from their own STL; assemblies instance per-part STLs
#    (metres, untranslated) through the scene graph in cad/out/boxes/*.json,
#    with each component's SolidWorks appearance RGB as Workbench object
#    colour. Ortho only; sidecars carry "engine" — score trends are only
#    comparable within one engine. parity_check.py measures silhouette IoU
#    between the backed-up and current renders (instanced-vs-monolith
#    baseline: 0.99+).

# 3. recompute composites/scores without rendering (e.g. after align edits)
uv run cad/comparisons/tools/composite.py [--only id1,id2]

# 4. selective model rebuild after fixing a part script (dependent assemblies refresh)
C:\src\SolidworksMCP-python\.venv\Scripts\python.exe -m doit part:dt_cone_gear
```

## Interactive posing — Blender pose studio

`pose_studio.py` opens a pair's model **and** its book reference in Blender and
lets you dial the manifest camera live against the overlay, instead of
hand-editing `az/el/roll/zoom/target` and re-rendering. No SolidWorks needed —
just `uv` + Blender.

```powershell
# export the STL cache once after any rebuild (same prerequisite as render_offline)
C:\src\SolidworksMCP-python\.venv\Scripts\python.exe cad\scripts\export_models.py
# launch — the script relaunches itself inside Blender's GUI
uv run cad/comparisons/tools/pose_studio.py --pair ch30-p003
```

`--pair` matches a manifest pair id or any substring. Point at a different
Blender with `--blender <path>` or `$HARMONIC_BLENDER` (default `Blender 5.1`).

In Blender, open the **Harmonic** tab of the N-panel (press `N`):

- **Build / Reload Scene** — loads the pair and seeds every slider from its saved pose.
- **Orientation / Target / Framing** — az/el/roll, the framing centre (the other 3 axes), zoom + lens (mm).
- **Reference** — book overlay opacity / scale / shift (shown in camera view only).
- **Navigate** — MMB orbit · Shift+MMB pan · scroll zoom. `Numpad 0` toggles camera view and drops you onto the camera's *exact* vantage — no jump. **Capture From View** bakes a free-orbit angle back into the pose; **Frame Model** recovers the orbit if it greys out.
- **Save Pose To Manifest** — writes az/el/roll/target/zoom/lens onto the pair.

The pose round-trips 1:1 with `render_offline.py`, so after saving,
`render_offline.py --only <id>` reproduces it exactly. **Create Pair** adds a
new id + model + reference to the manifest in place.

> Verify the camera behaviour after touching the studio: `pose_studio.py --pair
> <id> --shots <dir>` drives the real UI (build → toggle camera view → capture
> each state → quit) and drops before/after PNGs in `<dir>`.

Pair ids are `<model>--<source-id>`; `model` maps to
`cad/out/{sldprt,sldasm}/<dashed>.{SLDPRT,SLDASM}`. Camera convention:
az 0 / el 0 = SolidWorks Front, +az = camera toward the model's +X (right)
side, el = elevation; `target_mm`/`zoom` frame close-ups; poses are refined
by editing the manifest and re-rendering `--only <id>` (no rebuild needed).

## Head-less inspection — meshprobe

`pose_to_meshprobe.py` replays a manifest pose into
[meshprobe](https://github.com/pedropaulovc/meshprobe) — the same vantage,
head-less, on the assembly **GLB** instead of the STL cache. It reads a pose
(a `manifest.json` pair, a `findings/<pair>_deltas.json`, or a bare camera
dict) and **emits** the `meshprobe` command sequence (`open → view-orbit →
illumination-set → render-image`); it does not run meshprobe itself.

**Prerequisite — the machine GLB** at `cad/out/gltf/<dashed>.glb` (the same
metre-unit glTF `export_models.py` writes). Produce one either way:

```powershell
# from the SolidWorks seat: open a .SLDASM and SaveAs3 it to .glb
uv run python cad/scripts/export_glb.py <dir-with-the-assembly>/ha-harmonic-analyzer.SLDASM
# or add --fetch-glb below to pull gltf/<model>.glb from the latest release bundle
```

```powershell
# print the commands for one pair (id substring)
uv run cad/comparisons/tools/pose_to_meshprobe.py --pair ch30-p002

# actually render it: pipe the emitted commands to a shell (bash — see quoting note)
uv run cad/comparisons/tools/pose_to_meshprobe.py --pair ch30-p002 | bash
uv run meshprobe close --all            # stop the Blender daemon when done

# many poses, ONE open: --batch shares a single meshprobe session so the (large)
# GLB is imported once instead of re-opened per pair
uv run cad/comparisons/tools/pose_to_meshprobe.py --batch | bash

# just the computed params, no shell
uv run cad/comparisons/tools/pose_to_meshprobe.py --pair ch30-p002 --format json
```

The emitted commands invoke `uv run meshprobe` (so the pipe-to-`bash` flow works
without a global install; override with `--meshprobe`). Renders land in
`cad/comparisons/render/meshprobe/<id>.png`. Useful flags: `--batch` / `--session
<name>` (one shared session, open once), `--canvas WxH` (forces the render
canvas — **distance depends on its portrait/landscape aspect**, so pass it when
no reference image is available or the run warns about the landscape default),
`--glb <path>` / `--fetch-glb` (GLB source; the scene-bbox source tracks it),
`--boxes <path>` (explicit per-part boxes; required for `frame_components`
poses), `--blender <path>` (override; by default the emitted `open` omits it so
meshprobe locates Blender itself).

Mapping (verified against the `open` receipt): pose_studio model coords
`(x, y, z)` → meshprobe world `(x, −z, y)`; `azimuth = az − 90`,
`elevation = el`, roll passthrough; distance = the same fitted `cam_dist` as
`render_offline`. The GLB is metres and meshprobe reports/accepts mm, so the
default `--unit-scale 1.0` is correct.

> **PowerShell quoting**: the emitted `--projection-json '{…}'` uses bash
> single-quotes. On PowerShell run the pipe under `bash`/Git Bash, or use
> `--format json` and build the call yourself.

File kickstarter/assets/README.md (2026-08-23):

# Campaign assets

Inventory and specs. **Binaries do not live here** — renders come from the
build (`cad/out/`, gitignored), photographs from the logbook, and finished
campaign exports are uploaded to Kickstarter, not committed. This file tracks
what exists, what's missing, and to what spec.

## Specs
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

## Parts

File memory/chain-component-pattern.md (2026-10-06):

---
name: chain-component-pattern
description: Native SW Chain Component Pattern — how the paper-drive roller chain is built (pywin32 FeatureChainPattern + closed-spline path); path must be a sketch SEGMENT not the sketch feature
metadata:
  type: reference
---

> Identity migration: narrative references may use current filenames and paths; this does not date those names to the original finding. Dated observations and metrics, historical release paths, and identifiers in quoted or captured records retain their snapshot values. See the [subsystem identity guide](../cad/docs/subsystem-identities.md) for current identities and the old-to-current map.

## SHIPPED 2026-07-05 — `_insert_roller_chain` now uses the native chain pattern

The paper-drive roller chain is now built by a native **connected-linkage chain
component pattern** (adapter method `pattern_components_chain` →
`IFeatureManager.FeatureChainPattern`), replacing the manual per-link placement.
Full `doit`/standalone build + `verify:soundness` pass (58 links, DOF pattern=56,
0 interference, model healthy). Diagnostic: `diagnostics/diag_chain_pattern.py`
(exercises `_insert_roller_chain` in a fresh assembly). The pywin32 recipe below
is the one implemented.

## RESOLVED 2026-07-05 — the feature works; the blocker was the path selection type

Earlier this memory concluded the Chain Component Pattern was unusable via API
(CreateFeature → None across ~14 pywin32 + early-bound C# runs). **That was wrong.**
A UI macro-recording (`Macro1.swp`) of the working feature revealed the real cause:

- **The PATH must be selected as the sketch SEGMENT** —
  `SelectByID2("Arc1@Sketch1", "EXTSKETCHSEGMENT", …, mark=2)` — NOT the sketch
  feature (`"Sketch1"`, `"SKETCH"`). Selecting the sketch feature yields an invalid
  definition, so `CreateFeature` silently returns null (no error from
  `GetCreateFeatureErrors`). This one thing caused every failure.
- With the segment path, the docs route works verbatim: pre-select segment(2) +
  component(1) + path-link axis(256) [+ link2 512 / group2 2048/4096/8192/32768 for
  linkage] + align plane(16384) → `fm.CreateDefinition(swFmLocalChainPattern=112)` →
  set `PitchMethod`/`AlignMethod`/`Options`/`InstanceCount`/`FillPath` → `CreateFeature`.
  Verified live: count-driven gave 20 instances, `FillPath=True` filled to 13.
- **The property GETTERS are unreliable pre-commit** (read back 0/False right after a
  valid set) — ignore them; the SETTER still applies at `CreateFeature`. This false
  signal is what made the earlier runs look like "PropPut doesn't stick".
- `IFeatureManager.FeatureChainPattern(PitchMethod, FlipDirection, FillPath, Number,
  Spacing, GroupOneFlipPlane, GroupTwoChain, GroupTwoFlipPlane, AlignMethod, Options)`
  is a dedicated one-call alternative to CreateDefinition/CreateFeature (untested for fill).
- `sw_type_info.early_bound` is NOT required — the path-selection type was the whole issue.
  In-process `gencache.EnsureModule`/`CastTo` on the SW TLB still WEDGES the seat; don't.

## pywin32 recipe (the one to ship) — use FeatureChainPattern, not CreateFeature

Verified end-to-end in pywin32 on the real loop (58 alternating links, connected linkage):

1. **Path = a single CLOSED segment.** Author the loop as one closed **spline**
   (`add_spline` through dense `loop_point_tangent` samples + closing point) — the
   3-arc+line contour is NOT connected (segments share coords but have no coincidence
   relations, so `MakeSketchChain` forms 0 paths / `GetSketchPathCount`=0). Select it as
   `EXTSKETCHSEGMENT` (`"Spline1@Sketch1"`, mark 2).
2. **`CreateDefinition`/`CreateFeature` returns null under pywin32** even with everything
   right (works in early-bound C#, not late-bound pywin32 — a marshaling quirk of the
   feature-data object). **Use the dedicated one-call method instead:**
   `IFeatureManager.FeatureChainPattern(PitchMethod, FlipDirection, FillPath, Number,
   Spacing, GroupOneFlipPlane, GroupTwoChain, GroupTwoFlipPlane, AlignMethod, Options)`.
   It consumes the pre-selection and returns the feature. Connected linkage =
   `PitchMethod=2`, `GroupTwoChain=True`, `FillPath=True`, `AlignMethod=1`(tangent),
   `Options=1`(dynamic).
3. **Selections (marks):** path `EXTSKETCHSEGMENT`(2); group1 inner comp(1) + pins
   `Axis1`(256)/`Axis2`(512) + `Front Plane`(16384); group2 outer comp(2048) + pins
   `Axis1`(4096)/`Axis2`(8192) + `Front Plane`(32768). Seeds placed tangent (chord) so
   both pins sit ~on the path.
4. Non-integer fit leaves a one-link seam at the seed — RESOLVED by quantising the
   LOOP, not the pitch: `_chain.py` keeps `LINK_PITCH` at the exact #25 standard
   (6.35) and solves the slack-run SAG so `CENTRELINE_LEN == LINK_COUNT * pitch`
   with an even count (54) — the sag absorbs the residual, like a real chain
   (2026-07-06; was 58 stretched-pitch links with a seam risk).

**How to apply:** the native chain pattern is viable for the paper-drive roller chain
(`_insert_roller_chain` can be replaced). Author the loop path sketch, select the loop
as EXTSKETCHSEGMENT(s), place inner+outer seeds, use connected linkage (two groups) for
the alternating chain. Toolchain for API spikes: `csc.exe` (.NET Framework 4.0 at
`C:\Windows\Microsoft.NET\Framework64\v4.0.30319`) + the Interop DLLs at
`…\SOLIDWORKS 3DEXPERIENCE R2026x\SOLIDWORKS\api\redist\` (copy next to the exe — not in
GAC); reflect DispIds/signatures by loading the DLL. Makers = SW Connected Professional
(full modeling; only simulation/Xpress removed), so assembly features are all present.

---

## Original (superseded) investigation notes

The paper-drive roller chain is placed link-by-link on purpose
(`build_paper_drive_assembly._insert_roller_chain`). The docstring's claim that
the native **Chain Component Pattern** "rejects raw-COM CreateFeature" was
retested exhaustively live (2026-07-05, probe
`cad/scripts/diagnostics/probe_chain_pattern.py`, ~14 runs) per
[[verify-assumptions-live-sw]]. Result: the native feature is **not usable through
this adapter** — but the mechanism is subtler than "CreateFeature always None".

**What blocks it, in layers:**
1. `IFeatureManager.CreateDefinition(swFmLocalChainPattern=112)` returns a bare
   untyped `<COMObject <unknown>>` because the adapter *forces late binding*
   (`win32com.client.dynamic` — early binding breaks `OpenDoc6` pass-by-ref; see
   the SolidworksMCP-python COM-threading notes). On the untyped object, property
   PUTs are unreliable and `CreateFeature` returns `None`.
2. **The fix for creation is `sw_type_info.early_bound(data,
   "IChainPatternFeatureData")`** — wraps the dispatch in its typed gen_py class
   (dispid invoke, no makepy regen). With it, `CreateFeature` DOES return a
   feature. (Do NOT use `win32com.CastTo` — *"can not automate the makepy
   process"* — nor in-process `gencache.EnsureModule`/`EnsureDispatch` on the SW
   TLB: that is a multi-minute regen that **wedged the seat**, Not Responding
   >11 GB. Recover only via Platform-shortcut relaunch, never COM cold-start.)
3. Post-create configuration also works once typed: the feature (also
   `early_bound(feat, "IFeature")` so `GetDefinition`/`ModifyDefinition` resolve)
   → `GetDefinition` → `AccessSelections(model, None)` → set `FillPath`/
   `InstanceCount` (now they STICK) → `ModifyDefinition` → returns True.
4. **BUT the pattern generates ZERO instances** — FillPath=True and explicit
   InstanceCount=20 both `ModifyDefinition->True` yet no link copies appear
   (visually confirmed: render shows the loop path + the two seeds only). And
   **connected linkage** (`PitchMethod=2`, the alternating inner/outer chain the
   roller chain actually needs) can't be set at all — it stays 0.
5. Extra quirk: the single-group distance `CreateFeature` only succeeds when a
   (failing) two-group connected-linkage attempt runs *first* in the same process
   — a non-deterministic priming dependency.

**Bottom line:** even fully typed, the chain pattern is a degenerate empty
feature here — no instances, no connected linkage. Not viable for the roller
chain. Keep `_insert_roller_chain` (explicit placement); it produces the correct
alternating chain deterministically. The parts carry `Axis1`/`Axis2` (documented
PathLink1/2) and `_chain.loop_segments` exists for the path sketch, so the design
*intended* the native feature — it's blocked by the COM binding + the feature not
propagating instances, not by geometry. Relates to [[no-untested-failure-assumptions]].

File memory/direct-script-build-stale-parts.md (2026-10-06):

---
name: direct-script-build-stale-parts
description: Running a build_*.py assembly script directly uses whatever parts are on disk; stale parts fail mate-entity selection on named datums
metadata:
  type: feedback
---

> Identity migration: narrative references may use current filenames and paths; this does not date those names to the original finding. Dated observations and metrics, historical release paths, and identifiers in quoted or captured records retain their snapshot values. See the [subsystem identity guide](../cad/docs/subsystem-identities.md) for current identities and the old-to-current map.

Running an assembly `build_*.py` **directly** (e.g. `uv run python cad/scripts/build_frame_assembly.py`, to exercise a mate change live without going through doit) uses whatever part `.SLDPRT` files are already on disk — it does NOT rebuild stale parts first. `doit assembly:<stem>` would, because parts are its `file_dep`.

**Symptom:** the assembly build fails at a mate with `Failed to select mate entity N (AXIS/PLANE at '<Datum>@<part>-1')` — e.g. `crank axis@cone-swing-platform-1`, `CrankAxisSeat@cone-swing-platform-1`, `HandleSeat@crank-arm-1`, `SetScrewAxis@pen-frame-1`. Looks like a mate-code bug; it is actually a **stale part** on disk built before that named datum (`create_axis`/`create_plane` + `name_last_feature`) was added to the part's build script. A part can be *partially* stale (had some named datums but not the newest). (NB: the frame subassembly no longer mates to ANY named datum — every member is placed at its exact transform + one lock mate on a DEFAULT plane — so this symptom shows up in the drive-train/channel/pen/etc. assemblies, not the frame.)

**Fix:** rebuild the offending part(s) directly (e.g. `build_dt_cone_swing_platform.py`, `build_dt_crank_arm.py`, `build_pn_pen_frame.py`), confirming the datum feature is created (`create_axis <Name> OK` → `feature 'AxisN' -> '<Name>'`), then re-run the assembly. Iterate per referenced datum, or just rebuild all of the assembly's parts up front.

**To isolate "is this MY change or the environment?":** temporarily `git checkout <old-commit> -- <file>` in the submodule (e.g. revert `assembly.py` to the pre-migration AddMate5 version) and re-run — if the identical failure reproduces, the change is exonerated and it is a stale-part / env issue. This is how I confirmed the AddMate5→CreateMate migration did not cause the lag-screw failure.

**Verify freshness guard:** `verify.py --suite soundness <stem>` refuses a directly-built artefact with `STALE artefact, NOT verified ... changed since build` because the doit `.doit.db` ledger wasn't updated by the direct script. Bypass with `HARMONIC_VERIFY_ALLOW_STALE=1` when you know the artefact is genuinely fresh (you just built it). See [[single-assembly-fast-verify]].

**The INVERSE trap — direct build + script revert = permanently stale artefact
(v0.15.0 rocker-arm-support lug, 2026-07-05).** Direct-building a PART writes a
fresh artefact the ledger doesn't know about; if you then `git checkout --` the
script edit, the recorded digest MATCHES the reverted script again and doit
reads the task up-to-date FOREVER -- the out-of-band artefact (here: the
abandoned clamp-boss lug) ships through every "full" build. No CAD gate sees an
additive cosmetic change (no interference, DOF/pose clean); the RELEASE DIFF
render caught it (v0.15.0 shipped the lug; user's eye on diff_summary).
**Rule: after reverting a script whose part you built out-of-band, DELETE the
artefact** (SLDPRT+STL+PNGs, and its consuming .SLDASMs per
[[cache-partial-mix-dangle-remedy]]) so doit full-rebuilds. The remote cache is
NOT poisoned by this (a direct build never stores; the pre-edit clean artefact
stays cached under the unchanged recipe key), so a cache-on rebuild heals
instantly. Localize a suspect diff with vertex-nearest sampling on the two STLs
(added vs removed regions) -- see the v0.15.1 session.

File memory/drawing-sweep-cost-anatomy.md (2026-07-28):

---
name: drawing-sweep-cost-anatomy
description: Entity sweeps dominate a part drawing; kind 1 splits three near-equal ways (sweep 7.5s / COM reads 11.2s / _early_bound wrapper binding 7.0s — binding is NOT COM and is the only attackable third), kind 4 is a flat ~21s call; four ways to cut them were measured and all four failed
metadata:
  type: project
---

Measured 2026-07-28 on the live seat, after routing every sweep through the
traced `visible_view_entities` chokepoint (before that, 43.8 min of 193.7 min of
drawing build time sat inside `drawing.build` covered by NO child span).

**The two sweep kinds cost in opposite ways. Do not reason about "a sweep".**

| pick | sweep call | per-entity loop | entities |
|---|---|---|---|
| cone_gear circle (kind 1) | 7.0 s | **18.4 s** | 481 edges |
| crank_drive_gear circle (kind 1) | 8.3 s | **21.1 s** | 577 edges |
| crank_drive_gear tooth (kind 4) | **26.7 s** | 8.5 s | 9 silhouettes |
| spring_hook shank (kind 4) | **20.6 s** | 3.5 s | 6 silhouettes |

Kind 1 returns hundreds of edges cheaply and the classification loop is the
bill. Kind 4 makes SolidWorks derive outline geometry: ~21 s flat, *independent
of how few entities come back*.

**Inside the kind-1 loop the cost splits three near-equal ways** (cone_gear,
481 edges, 27.7 s, each timer bracketing exactly one operation):
sweep 7.5 s, `GetCurve()` 8.8 s (**18.2 ms** each), `_early_bound` 7.0 s
(7.3 ms x2 per edge), `IsCircle()` 2.0 s (4.2 ms), `CircleParams` 0.4 s
(3.4 ms x121).

An earlier version of this note said `GetCurve` was 24.6 ms and "the entire
bill". Wrong, and wrong in the way this file warns about: that timer also
enclosed the `_early_bound` of the returned curve, inflating the call by ~35%.
**Bracket one operation per timer, including the non-COM ones.**

**`_early_bound` is the lead worth pulling.** 7.0 s of 27.7 s, twice per edge
(the IEdge, then the returned ICurve), and it is NOT a COM round trip — it is
local wrapper resolution. It is therefore the only third of this cost
attackable without a different SolidWorks API. Untested: whether the wrapper
lookup memoises per interface. Measure before assuming.

**Four optimisations measured, four refuted (and one still open).**

0. **Memoising the `_early_bound` wrapper lookup.** UNTESTED — the one idea
   below that has not been refuted, and the measurement above says it is worth
   up to 7.0 s of a 27.7 s pick.
1. **Per-view memo of the sweep.** 0% hit rate — an audit of every call site
   found no drawing that sweeps the same view twice (each gear print picks a
   circle off `front` and at most a silhouette off `right`). A cross-call cache
   would also need invalidating on any visibility change, and a stale entity
   list picks the wrong edge SILENTLY.
2. **`IEdge::GetCurveParams2` as a cheap pre-filter** (2.6 ms, 10x cheaper than
   `GetCurve`), paying `GetCurve` only for closed edges. Refuted: a full circle
   does NOT report coincident endpoints — `closed=1` out of 121 circles.
3. **Start-point-radius pre-filter** (the trick `visible_tooth_tip_silhouette`
   uses). Not available to `visible_circle_edge`: sound only for entities
   coaxial with the view origin, and that helper is also called for OFF-AXIS
   holes (adjuster passages, flange hold-downs).
4. **Warming / reordering the kind-4 sweep**, on the theory that ~21 s for 6
   entities is one-time view resolution. Refuted: a second identical sweep on
   the same view in the same session measured 21.2 s against the first's 20.8 s.
   It recomputes every call.

**What is left.** Kind 4's only lever is calling it FEWER times — a
drawing-design question (does this print need a tooth-tip silhouette at all?),
not a helper-level one. Worth raising when the GD&T callouts get cut.

**Why:** the standing rule is that a drawing over 1 min signals something worth
investigating, and for the gear/spring prints the answer is the sweep, not the
recipe. See [[drawing-isolation-cost]] for the *assembly* drawing equivalent
(component isolation, a different loop) and [[drawing-fleet-timings-drift]] for
why a large total is not automatically a defect.

**How to apply:** read `curve_s`/`classify_s`/`params_s` and the child
`drawing.visible_entity_scan` span (`components`/`entities`/`entity_kind`) off
the span line before optimising — they say which of the four costs you are
looking at. Related: [[drawing-recipe-com-pitfalls]],
[[load-bearing-claims-need-a-repro]].

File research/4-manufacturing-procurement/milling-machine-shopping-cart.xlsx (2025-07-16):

Retailer | Category | Subcategory | Title | Price | URL
Amazon | Work-holding & Setup | V-Block Pair | Grizzly Industrial H5608 - V-Block Pair w/Clamps 1-5/8"Grizzly Industrial H5608 - V-Block Pair w/Clamps 1-5/8"Opens in a new tab | $27.90 | https://www.amazon.com/gp/product/B00012YD96/ref=ox_sc_act_title_delete_1?smid=ATVZV8WE1S2L8&psc=1
Amazon | Lubrication & Care | Threadlocker - High Strength | Loctite 88442 Red 272 High Temperature/Strength Thread Locker, 50 mL BottleLoctite 88442 Red 272 High Temperature/Strength Thread Locker, 50 mL BottleOpens in a new tab | $19.89 | https://www.amazon.com/gp/product/B00B749E1O/ref=ox_sc_act_title_delete_2?smid=AYST33XHDW8T2&psc=1
Amazon | Lubrication & Care | Threadlocker - Medium Strength | Loctite 1329467 243 Blue Medium Strength Threadlockers, 1.69 Ounces, 50 mL, 3/4" ThreadLoctite 1329467 243 Blue Medium Strength Threadlockers, 1.69 Ounces, 50 mL, 3/4" ThreadOpens in a new tab | $13.84 | https://www.amazon.com/gp/product/B009I2UC3Q/ref=ox_sc_act_title_delete_3?smid=A1638BYNHEKCKQ&psc=1
Amazon | Lubrication & Care | Oil can / pump oiler | Junchi Hand Pump Oiler Can Professional Level 8 oz. Capacity Pump Oiler with Metal & Long Flex SpoutJunchi Hand Pump Oiler Can Professional Level 8 oz. Capacity Pump Oiler with Metal & Long Flex SpoutOpens in a new tab | $7.99 | https://www.amazon.com/gp/product/B07H8471MZ/ref=ox_sc_act_title_delete_4?smid=A31O2VHCJ8BK5N&psc=1
Amazon | Lubrication & Care | Lubrication spray (WD-40) | WD-40 Multi-Use Product with Smart Straw Sprays 2 Ways, 11 OZWD-40 Multi-Use Product with Smart Straw Sprays 2 Ways, 11 OZOpens in a new tab | $15.93 | https://www.amazon.com/gp/product/B000NV5PRE/ref=ox_sc_act_title_delete_5?smid=A139UT6SRHLIZJ&psc=1
Amazon | Lubrication & Care | Cutting fluids | TAP Magic 10016E EP-XTRAOZ ONE Friendly Cutting FLUIDS - 16 OZ. SPOUT TOPTAP Magic 10016E EP-XTRAOZ ONE Friendly Cutting FLUIDS - 16 OZ. SPOUT TOPOpens in a new tab | $13.30 | https://www.amazon.com/gp/product/B00DHMHSGM/ref=ox_sc_act_title_delete_6?smid=ATVPDKIKX0DER&psc=1
Amazon | Lubrication & Care | Hydraulic oil | ELBALUBES S-HYD 22 Industrial Hydraulic Oil | Zinc-Free Ashless | Cross Reference to Mobil VELOCITE 10, Shell TELLUS 22, Rando 22, NUTO 22 (1 QT)ELBALUBES S-HYD 22 Industrial Hydraulic Oil | Zinc-Free Ashless | Cross Reference to Mobil VELOCITE 10, Shell TELLUS 22, Rando 22, NUTO 22 (1 QT)Opens in a new tab | $29.70 | https://www.amazon.com/gp/product/B09RQ1W7TY/ref=ox_sc_act_title_delete_7?smid=A3JWDRCAVRM7K7&psc=1
Amazon | Lubrication & Care | Oil can / pump oiler | GOLDENROD (625) Pistol Pump Oiler with Straight Spout - 10 oz. CapacityGOLDENROD (625) Pistol Pump Oiler with Straight Spout - 10 oz. CapacityOpens in a new tab | $21.49 | https://www.amazon.com/gp/product/B000VA93MK/ref=ox_sc_act_title_delete_8?smid=ATVPDKIKX0DER&psc=1
Amazon | Lubrication & Care | Mobil Vactra No. 2 way-oil (1 gal) | Mobil 100772 Vactra Oil No.2 Way Oil, 1 galMobil 100772 Vactra Oil No.2 Way Oil, 1 galOpens in a new tab | $49.95 | https://www.amazon.com/gp/product/B07B7XZKVF/ref=ox_sc_act_title_delete_9?smid=A17BZOLZKLWVN9&psc=1
Amazon | Cutting Tools | 2″ boring-head kit, R8 + ½″ bars | findmall 9pcs 2" Boring Head R8 Shank Boring Tool Set 1/2" Carbide Boring Bar Set Milling Fit for Milling Machinefindmall 9pcs 2" Boring Head R8 Shank Boring Tool Set 1/2" Carbide Boring Bar Set Milling Fit for Milling MachineOpens in a new tab | $47.30 | https://www.amazon.com/gp/product/B07TFDK7L2/ref=ox_sc_act_title_delete_10?smid=A30FABLYMW48NQ&psc=1
Amazon | Cutting Tools | 3″ fly-cutter with R8 shank | 2" Inch II 50 mm Head Diameter Fly Cutter for milling & Lathe Machine with Replaceable Carbide Insert bit Indexable Tool - R8 Shank2" Inch II 50 mm Head Diameter Fly Cutter for milling & Lathe Machine with Replaceable Carbide Insert bit Indexable Tool - R8 ShankOpens in a new tab | $89.69 | https://www.amazon.com/gp/product/B0CBPWYX2B/ref=ox_sc_act_title_delete_11?smid=A2WWL53CQK8WP1&psc=1
Amazon | Cutting Tools | 3-piece countersink/deburr set – ¼″ shank, 82° | AFA Tooling - Deburring Tool & 2 Countersink Hand Reamers with 10 Blades - Works on Metal, Resin, PVC Pipes, Copper, Plastic and 3D Printed Edges - Plumbing & 3D Printing Burr Removal Reamer ToolAFA Tooling - Deburring Tool & 2 Countersink Hand Reamers with 10 Blades - Works on Metal, Resin, PVC Pipes, Copper, Plastic and 3D Printed Edges - Plumbing & 3D Pr…Opens in a new tab | $39.95 | https://www.amazon.com/gp/product/B08SLBT6SJ/ref=ox_sc_act_title_delete_12?smid=AWUG75A0QJGB8&psc=1
Amazon | Cutting Tools | #1-#5 center-drill set | 7 Pieces Center Drill Bits Set, M2 High Speed Steel 60-Degree Angle Center Drill Bits Kit Countersink Tools for Lathe Metalworking Size 1.0 1.5 2.0 2.5 3.0 4.0 5.07 Pieces Center Drill Bits Set, M2 High Speed Steel 60-Degree Angle Center Drill Bits Kit Countersink Tools for Lathe Metalworking Size 1.0 1.5 2.0 2.5 3.0 4.0 5.0Opens in a new tab | $17.99 | https://www.amazon.com/gp/product/B08ZYXXX1Y/ref=ox_sc_act_title_delete_13?smid=A1ON01QALUAPQH&psc=1
Amazon | Cutting Tools | 90° spot-drill set | Geevorks Spotting Drill Bit, M42 HSS High Speed Steel Drill Bit Set,7PCS 90 Degree Drilling Chamfering Tool - 3 4 5 6 8 10 12mmGeevorks Spotting Drill Bit, M42 HSS High Speed Steel Drill Bit Set,7PCS 90 Degree Drilling Chamfering Tool - 3 4 5 6 8 10 12mmOpens in a new tab | $28.69 | https://www.amazon.com/gp/product/B09NKZMT19/ref=ox_sc_act_title_delete_14?smid=A1DOA4F0QJWJ8F&psc=1
Amazon | Measurement & Calibration | Telescoping gage set | Beslands 6 Pc Telescoping Gage Set, 5/16" - 6" Range, T-Bore Hole Gauges w/Pouch, High Precision Telescopic Bore Gauge T-Gage Set (5/16" to 6")Beslands 6 Pc Telescoping Gage Set, 5/16" - 6" Range, T-Bore Hole Gauges w/Pouch, High Precision Telescopic Bore Gauge T-Gage Set (5/16" to 6")Opens in a new tab | $20.80 | https://www.amazon.com/gp/product/B08MQCTTM3/ref=ox_sc_act_title_delete_15?smid=A258KNTLTSH5TN&psc=1
Amazon | Cutting Tools | HSS end-mill set | 20 PC Titanium Nitride Coated End Mill Set - 4 & 2 Flute Tin End Mill for Milling Machines20 PC Titanium Nitride Coated End Mill Set - 4 & 2 Flute Tin End Mill for Milling MachinesOpens in a new tab | $109.81 | https://www.amazon.com/gp/product/B01M17VXH5/ref=ox_sc_act_title_delete_16?smid=A1D02W4307VYI4&psc=1
Amazon | Cutting Tools | HSS end-mill set | AUTOTOOLHOME 1/8" 3/16" 1/4" 5/16" 3/8" 1/2" high Speed Steel HSS 4 Flute Straight End Mill Cutter 5/32" 1/16" Set of 8AUTOTOOLHOME 1/8" 3/16" 1/4" 5/16" 3/8" 1/2" high Speed Steel HSS 4 Flute Straight End Mill Cutter 5/32" 1/16" Set of 8Opens in a new tab | $13.99 | https://www.amazon.com/gp/product/B00ZZYJU2U/ref=ox_sc_act_title_delete_17?smid=A1EPDRGYFZ55O7&psc=1
Amazon | Cutting Tools | Carbide end-mill set | sisona 1/8" 3/16" 1/4" 5/16" 3/8" 1/2” 2 Flute Carbide End Mill Bits Set - 6pcs Carbide Upcut CNC Spiral Router Milling Bits for Steel - Square Nose, TISIN Coated,Center Cuttingsisona 1/8" 3/16" 1/4" 5/16" 3/8" 1/2” 2 Flute Carbide End Mill Bits Set - 6pcs Carbide Upcut CNC Spiral Router Milling Bits for Steel - Square Nose, TISIN Coated,C…Opens in a new tab | $59.99 | https://www.amazon.com/gp/product/B0C53L47X6/ref=ox_sc_act_title_delete_18?smid=A188XA8BP85GZC&psc=1
Amazon | Cutting Tools | Carbide end-mill set | sisona 1/8" 3/16" 1/4" 5/16" 3/8" Carbide End Mills Set - Solid Carbide (Tungsten Carbide + Cobalt) - 5Pcs 4 Fulte CNC Mill Bits for Steel - TISIN Coatedsisona 1/8" 3/16" 1/4" 5/16" 3/8" Carbide End Mills Set - Solid Carbide (Tungsten Carbide + Cobalt) - 5Pcs 4 Fulte CNC Mill Bits for Steel - TISIN CoatedOpens in a new tab | $39.99 | https://www.amazon.com/gp/product/B0B1HC94QX/ref=ox_sc_act_title_delete_19?smid=A188XA8BP85GZC&psc=1
Amazon | Tool-holding (R8 spindle) | Keyless ½″ R8 drill chuck | Earl Diamond Super Heavy Duty Drill Chuck 1/2" Capacity with R8 Shank Precision Integrated & K32 Key (R8-B16)Earl Diamond Super Heavy Duty Drill Chuck 1/2" Capacity with R8 Shank Precision Integrated & K32 Key (R8-B16)Opens in a new tab | $47.69 | https://www.amazon.com/gp/product/B081SV3K2W/ref=ox_sc_act_title_delete_20?smid=A9UCBMF1YAQKQ&psc=1
Amazon | Tool-holding (R8 spindle) | 23-piece R8 collet set, 1/16–¾″ by 1/32″ | BTSHUB 23pc 1/16-3/4 inches Precision R8 Collets Set Mill Chuck Holder Hardened T.I.R. 0.0006" LatheBTSHUB 23pc 1/16-3/4 inches Precision R8 Collets Set Mill Chuck Holder Hardened T.I.R. 0.0006" LatheOpens in a new tab | $79.59 | https://www.amazon.com/gp/product/B08HWK5D51/ref=ox_sc_act_title_delete_21?smid=A2WQGZUJKBKB7&psc=1
Amazon | Measurement & Calibration | 81-piece grade-B steel gauge-block set | Accusize Industrial Tools Precision 81-Piece Steel Gauge Block Set, Grade B Accuracy, Corrosion-Resistant, P900-S581Accusize Industrial Tools Precision 81-Piece Steel Gauge Block Set, Grade B Accuracy, Corrosion-Resistant, P900-S581Opens in a new tab | $148.00 | https://www.amazon.com/gp/product/B00HNU3JDU/ref=ox_sc_act_title_delete_22?smid=A27F0FNA6WTMGT&psc=1
Amazon | Measurement & Calibration | Uncategorized | Accusize Industrial Tools 0.03'' x 0.0005'' Dial Test Indicator in Fitted Box, P900-S108Accusize Industrial Tools 0.03'' x 0.0005'' Dial Test Indicator in Fitted Box, P900-S108Opens in a new tab | $55.90 | https://www.amazon.com/gp/product/B00UNNLVCU/ref=ox_sc_act_title_delete_23?smid=A27F0FNA6WTMGT&psc=1
Amazon | Measurement & Calibration | Dial indicator, 1″ travel, 0.0005″ grad. | Qnkaa Dial Indicator with Magnetic Base Holder Fine Adjustable Long Arm 0-1" Magnetic Dial Indicator Professional Dial Gauge 0.001"Qnkaa Dial Indicator with Magnetic Base Holder Fine Adjustable Long Arm 0-1" Magnetic Dial Indicator Professional Dial Gauge 0.001"Opens in a new tab | $40.99 | https://www.amazon.com/gp/product/B08DFKCWX4/ref=ox_sc_act_title_delete_24?smid=A1634YBW6XD05X&psc=1
Amazon | Measurement & Calibration | Uncategorized | Dial Indicator, SAE, 0.0005 Resolution (Half a Thousandth), 1" Travel, Accuracy 0.001" per 1", Machined Anodized Aluminum Body, Vertical Lug Back, Dial Test Indicator DI-1”Dial Indicator, SAE, 0.0005 Resolution (Half a Thousandth), 1" Travel, Accuracy 0.001" per 1", Machined Anodized Aluminum Body, Vertical Lug Back, Dial Test Indicator DI-1”Opens in a new tab | $23.99 | https://www.amazon.com/gp/product/B01JTWXBN2/ref=ox_sc_act_title_delete_25?smid=A1F0ZX9W2WURWY&psc=1
Amazon | Measurement & Calibration | 0-1/1-2/2-3/3-4″ outside micrometer set (0.0001″) | Outside Micrometer Set, HDLNKAK 0-3" Machinist Micrometer, 3 Pcs Machinist Tool Set, 0.0001" Graduation Micrometer Set, Alloy Precision Micrometer, Micrometer Standard Set with CaseOutside Micrometer Set, HDLNKAK 0-3" Machinist Micrometer, 3 Pcs Machinist Tool Set, 0.0001" Graduation Micrometer Set, Alloy Precision Micrometer, Micrometer Sta…Opens in a new tab | $39.99 | https://www.amazon.com/gp/product/B0CLDPXFVZ/ref=ox_sc_act_title_delete_26?smid=A25IZS0VCM0EW6&psc=1
Amazon | Work-holding & Setup | 10-pair 1/8″ parallels set (6″ long) | Accusize Industrial Tools 1/8'' Thickness 10 Pairs Precision Parallel Sets, 6'' Length, Eg10-1400Accusize Industrial Tools 1/8'' Thickness 10 Pairs Precision Parallel Sets, 6'' Length, Eg10-1400Opens in a new tab | $65.36 | https://www.amazon.com/gp/product/B00RZQSGU8/ref=ox_sc_act_title_delete_27?smid=A27F0FNA6WTMGT&psc=1
Amazon | Work-holding & Setup | Mitutoyo 3⁄8″ mechanical edge finder | Mitutoyo 050101, Edge Finder, 3/8" Dia. Shank, .200" Dia. TipMitutoyo 050101, Edge Finder, 3/8" Dia. Shank, .200" Dia. TipOpens in a new tab | $16.55 | https://www.amazon.com/gp/product/B002SG7PPC/ref=ox_sc_act_title_delete_28?smid=ATVPDKIKX0DER&psc=1
Amazon | Work-holding & Setup | 1-2-3 precision blocks, matched pair | LLDSIMEX Pair 1" x 2" x 3" Precision Steel 1-2-3 123 Blocks 23 HolesLLDSIMEX Pair 1" x 2" x 3" Precision Steel 1-2-3 123 Blocks 23 HolesOpens in a new tab | $18.49 | https://www.amazon.com/gp/product/B07QWSL7TJ/ref=ox_sc_act_title_delete_29?smid=A1QWMVX117O8XO&psc=1
Amazon | Work-holding & Setup | 58-piece ½″ T-slot clamping/hold-down kit | 58Pc T-Slot Clamping Kit Mill Machinist Set Table Slots: 1/2"58Pc T-Slot Clamping Kit Mill Machinist Set Table Slots: 1/2"Opens in a new tab | $59.99 | https://www.amazon.com/gp/product/B07PRZ533T/ref=ox_sc_act_title_delete_30?smid=A1QWMVX117O8XO&psc=1
Amazon | Work-holding & Setup | Kurt-style 4″ CrossOver milling vise (DX4) | VEVOR 6 Inch ACCU Lock Down Vise Precision Milling Vice 6 Inch Jaw Width Drill Press Vise Milling Drilling Machine Bench Clamp Clamping Vice (6'')VEVOR 6 Inch ACCU Lock Down Vise Precision Milling Vice 6 Inch Jaw Width Drill Press Vise Milling Drilling Machine Bench Clamp Clamping Vice (6'')Opens in a new tab | $119.99 | https://www.amazon.com/gp/product/B0CY2HV4N1/ref=ox_sc_act_title_delete_31?smid=ATVPDKIKX0DER&psc=1

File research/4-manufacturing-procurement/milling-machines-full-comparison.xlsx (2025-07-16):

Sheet: Sheet1
Model | Weight (kg) | Quill Travel (mm) | CNC‑convertible? | 3‑Axis DRO in box? | Power‑feed? | Motor (HP/type) | Ball / Lead‑screw | Box‑way? | Column style | Spindle Speed (RPM) | Spindle Taper | Price (USD)
ZX50C gear‑head | 500 | 120 | Yes | Optional | No | 1.5 kW brushless AC | Leadscrew | No | Round column | 40–1400 (8‑step) | MT4 / R8 | $1,050–1,300
PM‑932M | 499 | 127 | Yes | Optional | Optional X/Z | 1.5 HP AC gear‑head | Leadscrew | No | Tall dovetail stack | 90–1970 (6‑step) | R8 | $2,799
Grizzly G0760 | 385 | 119 | Yes | No | Yes – X‑axis | 2 HP AC gear‑head | Leadscrew | No | Round column | 140–2436 (12‑step) | R8 | $3,105
PM‑833TV | 363 | 121 | Yes | No | Optional X | 2 HP AC + VFD | Leadscrew | No | Tall dovetail stack | 50–3200 (variable) | R8 | $4,699
Grizzly G0705 | 340 | 119 | Yes | No | No | 2 HP AC gear‑head | Leadscrew | No | Round column | 140–2436 (12‑step) | R8 | $2,905
ZX45 gear‑head | 300 | 120 | Yes | Optional | Optional | 2 HP brushless AC | Leadscrew | No | Tall dovetail stack | 95–1750 (6‑step) | R8 | $1,098–1,635
ZX40 gear‑head | 300 | 120 | Yes | No | Optional | 1.5 kW brushless AC | Leadscrew | No | Tall dovetail stack | 100–2080 (12‑step) | MT3 / R8 | $1,100–1,200
ZX7032 round‑column | 280 | 130 | Yes | No | No | 0.75 kW brushless AC | Leadscrew | No | Round column | 100–2150 (12‑step) | MT3 | $150+
ZX7045 square‑column | 270 | 120 | Yes | Optional | X‑axis feed option | 1.1 kW brushless AC | Leadscrew | No | Tall dovetail stack | 75–3200 (12‑step) | R8 | $1,500–1,900
Grizzly G0935 | 260 |  | Possible | Yes | No | 1.5 HP AC + VFD | Leadscrew | No | Tall dovetail stack | 80–5000 (2‑range) | R8 | $4,337
PM‑30MV | 240 | 76 | Yes | Optional | Optional X | 2 HP brushless DC | Leadscrew | No | Tall dovetail stack | 50–3000 (variable) | R8 | $2,999
PM‑727M | 234 | 76 | Yes | No | Optional X | 1 HP AC gear‑head | Leadscrew | No | Tall dovetail stack | 115–1700 (6‑step) | R8 | $2,699
PM‑727V | 234 | 76 | Yes | No | Optional X | 1.5 HP AC + VFD | Leadscrew | No | Tall dovetail stack | 40–3000 (variable) | R8 | $2,899
ZX32 compact | 232 | 85 | Yes | No | No | 0.75 kW brushless AC | Leadscrew | No | Round column | 95–1420 (6‑step) | MT3 / R8 | $1,100–1,200
Grizzly G9729 | 200 | 64 | No | No | No | 0.75 HP AC | Leadscrew | No | Combo (round) | 175–1425 (7‑step) | MT4 | $2,852
ZX7025 round‑column | 190 | 110 | Yes | No | No | 0.75–1.1 kW brushless AC | Leadscrew | No | Round column | 290–2150 (5‑step) | MT3 | $1,300
PM‑728VT | 186 | 76 | Yes | Optional | Optional X | 1 HP brushless DC | Leadscrew (ballscrew kit avail.) | No | Tall dovetail stack | 75–4000 (variable) | R8 | $3,699
Grizzly G0759 | 178 | 51 | Yes | Yes | No | 1 HP DC brushed | Leadscrew | No | Tall dovetail stack | 50–2250 (2‑range) | R8 | $3,469
PM‑25MV | 159 | 51 | Yes | Optional | Optional X | 0.75 HP brushless DC | Leadscrew | No | Tall dovetail stack | 50–2500 (variable) | R8 | $2,399
Grizzly G0758 | 145 | 51 | Yes | No | No | 0.75 HP DC brushed | Leadscrew | No | Tall dovetail stack | 50–2000 (2‑range) | R8 | $1,723
Grizzly G0781 | 62 | 51 | Limited | No | No | 0.75 HP brushed universal | Leadscrew | No | Short dovetail | 50–2000 (variable) | R8 | $1,195

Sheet: Sheet2
Model | Price | URL
32VL | $1120 | https://www.alibaba.com/product-detail/RM-32VL-1500W-High-Precision-Manual_1601460154023.html
3H | $2,500‑3,000 | https://www.alibaba.com/product-detail/Hot-Selling-Vertical-Horizontal-Turret-Universal_1601406791912.html
4H | $2,580‑2,980 | https://www.alibaba.com/product-detail/New-High-Quality-4H-Spindle-Turret_1601488716151.html
4H/5HM | $2,300‑2,400 | https://www.alibaba.com/product-detail/Cheap-Price-Semi-Automatic-Universal-Milling_1601346869947.html
CTZX32 | $1,180‑1,400 | https://www.alibaba.com/product-detail/CTZX32-Multi-Function-Variable-Speed-Drilling_1601457987228.html
GD400 | $1450 | https://www.alibaba.com/product-detail/Metal-Milling-Machine-Automatic-Drilling-Machine_1600519579683.html
MW0800 | $2,500‑3,000 | https://www.alibaba.com/product-detail/-Handy-Age-Geared-Head-Drilling_10000012150659.html
NT4 | $1,700‑1,800 | https://www.alibaba.com/product-detail/Multifunctional-Zx50p-Manual-Mill-Light-Duty_1601417270701.html
RM32V | $1,195‑1,295 | https://www.alibaba.com/product-detail/ZX50C-Back-Gear-Bench-Milling-Machine_1601045210862.html
RMZAY7045FG | $1,820‑2,000 | https://www.alibaba.com/product-detail/ZAY7045FG-Medium-Size-Universal-Milling-Machine_1601435290923.html
X6325 | $2,100‑2,600 | https://www.alibaba.com/product-detail/High-Quality-X6325-Vertical-Milling-Machine_1601392089795.html
XQ6032 | $1,800‑2,400 | https://www.alibaba.com/product-detail/XQ6032-Brand-New-Manual-Milling-Machine_1601445965212.html
YS3B | $1745 | https://www.alibaba.com/product-detail/YS3B-Medium-Size-Bench-Milling-Machine_1601428796169.html
ZAY7032 | $1,300‑1,500 | https://www.alibaba.com/product-detail/China-Metal-ZAY7032-Drilling-Milling-Machine_1601397051706.html
ZAY7045FG | $1,820‑2,000 | https://www.alibaba.com/product-detail/ZAY7045FG-Metal-Milling-Machine_1601435290923.html
ZAY7532M | $1500 | https://www.alibaba.com/product-detail/Universal-Milling-Drilling-Machine-ZAY7532-Manual_1601375657443.html
ZK9325 | $1,420‑1,650 | https://www.alibaba.com/product-detail/ZK9325-Variable-Speed-Drilling-Milling-Machine_1601382568433.html
ZX32G | $2185 | https://www.alibaba.com/product-detail/ZX32G-Small-Industrial-Grade-Vertical-Bench_1601345420245.html
ZX40 | $1500 | https://www.alibaba.com/product-detail/Light-Digital-Display-No-4-Turret_1601294919090.html
ZX45 | $1,098‑1,635 | https://www.alibaba.com/product-detail/Bench-Mini-Milling-and-Drilling-Machine_1601244043115.html
ZX45 | $1015 | https://www.alibaba.com/product-detail/Drilling-Milling-Tapping-Machine-High-Quality_1601451064852.html
ZX50 | $1099 | https://www.alibaba.com/product-detail/ZX50c-Mini-Manual-Drilling-Milling-Machine_1601041228635.html
ZX50C | $1,490‑1,770 | https://www.alibaba.com/product-detail/ZX50C-Bench-Top-Manual-Drilling-Milling_1600528570559.html
ZX50C | $1950 | https://www.alibaba.com/product-detail/Manual-BoRui-ZX50C-Milling-and-Drilling_62512870321.html
ZX50CM | $1,700‑1,800 | https://www.alibaba.com/product-detail/ZX50CM-High-Efficiency-Vertical-CNC-ZX50C_1601484388276.html
ZX5325M | $2,300‑3,000 | https://www.alibaba.com/product-detail/ZX5325M-Universal-Vertical-Milling-Machine_1601428043572.html
ZX6350C | $1,650‑1,750 | https://www.alibaba.com/product-detail/ZX6350C-Combination-Drilling-Milling-Machine_1600528743725.html
ZX6350T | $2200 | https://www.alibaba.com/product-detail/ZX6350T-Vertical-Horizontal-Drilling-Milling_1600522417289.html
ZX6350Z | $2,300‑3,000 | https://www.alibaba.com/product-detail/ZX6350Z-Universal-Milling-Drilling-Machine_1600539136821.html
ZX7025 | $1500 | https://www.alibaba.com/product-detail/ZX7025-Bench-Type-Drilling-Milling-Machine_1600705331436.html
ZX7045/1 | $1,100‑1,300 | https://www.alibaba.com/product-detail/ZX7045-1-Heavy-Duty-Bench-Drilling_1600463633932.html
ZX7125C | $2,500‑3,000 | https://www.alibaba.com/product-detail/ZX7125C-Benchtop-Universal-Milling-Drilling_62506475845.html
ZX75 | $1,700‑1,750 | https://www.alibaba.com/product-detail/ZX75-Turret-Vertical-Horizontal-Milling_1600511626267.html
ZX7550 | $2500 | https://www.alibaba.com/product-detail/ZX7550-Mini-Vertical-Universal-Milling-Machine_1601453622185.html
ZX7550C | $2569 | https://www.alibaba.com/product-detail/ANDUUK-High-precision-ZX7550C-ZX7550CW-Vertical_1601392126870.html
ZX7550CW | $1,389‑1,598 | https://www.alibaba.com/product-detail/ZX7550CW-Vertical-And-Horizontal-Milling_1600483653877.html
ZX7550CW/1 | $1,700‑1,800 | https://www.alibaba.com/product-detail/ZX7550CW-1-Combination-Milling-Machine_1600484006511.html
ZX75S | $1795 | https://www.alibaba.com/product-detail/ZX75S-Small-Manual-Milling-Drilling-Machine_1601455379325.html
ZX75VS | $1995 | https://www.alibaba.com/product-detail/ZX75VS-Variable-Speed-Vertical-Milling-Machine_1601454937388.html

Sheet: Milling_Machines___Unit_Price__
model | title | range of spindle speed(r.p.m) | price_usd | weight (kg) | spindle taper | source_file | warranty | lead time (days) | dimension_x_mm | dimension_y_mm | dimension_z_mm | table_travel_x_mm | table_travel_y_mm | table_travel_z_mm | other_props
3H | Hot Selling Vertical Horizontal Turret Universal 3H Turret Milling Machine Manual Mills 3 Axes for Manufacturing Plant | 65 - 5440 r.p.m | 3000 | 1500 | ISO40 | Hot-Selling-Vertical-Horizontal-Turret-Universal_1601406791912.html.txt | 1 Year | 20 |  |  |  | 780 | 400 | 420 | {"quantity (sets)": "1 - 10", "wuhan mairuiduo trading co., ltd.": "2 yrs", "voltage": "2.2KW", "max. table load(kg)": "100", "product descriptions from the supplier": "1 - 9 sets", "1 - 9 sets": "$3,000", "10 - 99 sets": "$2,800", ">= 100 sets": "$2,500", "shipping": "Shipping fee and delivery date to be negotiated. Chat with supplier now for more details.", "send inquiry": "Chat now", "spindle_speed_min_rpm": 65, "spindle_speed_max_rpm": 5440}
4H | New High Quality 4H Spindle Turret Milling Machine Universal Vertical 220V General Purpose Manual Mills | 80 - 5440 r.p.m | 2980 | 1400 | ISO40, R8 | New-High-Quality-4H-Spindle-Turret_1601488716151.html.txt | 1 Year | 1 | 1550 | 1650 | 2250 | 780 | 400 | 400 | {"quantity (pieces)": "1 - 1", "voltage": "220v 380v", "max. table load(kg)": "400", "dimension(l*w*h)": "1550*1650*2250mm", "t slot(number-width-pitch)": "3-16-65mm", "spindle travel": "127mm", "main motor power": "2.2", "head rotation (front - rear)": "Â±45Â°", "head rotation (left - right )": "Â±90Â°", "single package size": "155X165X225 cm", "single gross weight": "1400.000 KG", "customization options": "Chat now", "customizable": "1 - 29 pieces", "1 - 29 pieces": "$2,980", ">= 30 pieces": "$2,580", "shipping": "Shipping fee and delivery date to be negotiated. Chat with supplier now for more details.", "send inquiry": "Chat now", "spindle_speed_min_rpm": 80, "spindle_speed_max_rpm": 5440}
4H | Cheap Price Semi-Automatic Universal Milling Machine Vertical Turret 4H/5H Manual Mills | 75 - 4550 | 2400 | 1300 | R8 | Cheap-Price-Semi-Automatic-Universal-Milling_1601346869947.html.txt | 1 Year | 15 | 1566 | 1650 | 2100 | 750 | 350 | 300 | {"quantity (sets)": "1 - 1", "turret milling machine": "4h R8 Spindle Milling Machine", "small milling machine": "4h Vertical Turret Milling Machine", "no reviews yet": "#16", "custom manufacturer": "1 yr", "voltage": "220V, 380V", "max. table load(kg)": "350", "dimension(l*w*h)": "1566x1650x2100", "customization options": "Chat now", "customizable": "1 - 2 sets", "1 - 2 sets": "$2,400", ">= 3 sets": "$2,300", "shipping": "Shipping fee and delivery date to be negotiated. Chat with supplier now for more details.", "send inquiry": "Chat now"}
ZX40 | Light Digital Display No. 4 Turret Milling Machine Second-hand Machine and Small Manual Drilling and Milling Machine ZX40 | 0 - 5000 r.p.m | 1500 | 1250 | NT30 | Light-Digital-Display-No-4-Turret_1601294919090.html.txt | 1 Year | 10 | 150 | 85 | 230 | 1600 | 600 | 480 | {"quantity (sets)": "1 - 1", "voltage": "380", "max. table load(kg)": "599", "dimension(l*w*h)": "150*85*230", "machinery test report": "Not Available", "warranty of core components": "1 Year", "single package size": "1200X85X230 cm", "single gross weight": "1250.000 kg", "product descriptions from the supplier": ">= 1 sets", ">= 1 sets": "$1,500", "shipping": "Shipping fee and delivery date to be negotiated. Chat with supplier now for more details.", "send inquiry": "Chat now", "spindle_speed_min_rpm": 5000, "spindle_speed_max_rpm": 5000}
ZAY7532 ZAY7540 ZAY7545 ZAY7550 | Universal Milling Drilling Machine ZAY7532 Manual Quill Feed Vertical Horizontal Milling Machine ZAY7532/1 | 10 - 1110 r.p.m | 1500 | 1030 | ISO40 | Universal-Milling-Drilling-Machine-ZAY7532-Manual_1601375657443.html.txt | 12 months | 35 | 1020 | 1350 | 1850 |  | 300 | 585 | {"quantity (sets)": "1 - 1", "tengzhou hoton machinery co., ltd.": "7 yrs", "voltage": "380V 220V 240V or 440V", "max. table load(kg)": "0", "dimension(l*w*h)": "1020x1350x1850mm", "provided": "CNC or Not", "cnc or not": "Normal", "table size": "800x240mm", "spindle travel": "130mm", "weight": "1100KG", "power(w)": "0.75KW", "customization options": "Chat now", "customizable": ">= 1 sets", ">= 1 sets": "$1,500", "shipping": "Shipping fee and delivery date to be negotiated. Chat with supplier now for more details.", "send inquiry": "Chat now", "used cnc milling machine": "5 axis milling machine", "spindle_speed_min_rpm": 10, "spindle_speed_max_rpm": 1110}
ZX7550CW | ANDUUK High precision ZX7550C ZX7550CW Vertical and Horizontal Milling Machine manual mills | 115 - 1750 r.p.m | 2569 | 1000 | MT4 | ANDUUK-High-precision-ZX7550C-ZX7550CW-Vertical_1601392126870.html.txt | 3 months | 31 | 1280 | 1285 | 2080 | 500 | 230 | 490 | {"quantity (pieces)": "1 - 1", "drilling milling": "zx7550cw Drilling Milling", "no reviews yet": "1 sold", "1 sold": "Hebei Hebing Technology Co., Ltd.,", "hebei hebing technology co., ltd.,": "1 yr", "voltage": "380v 220v", "max. table load(kg)": "100", "dimension(l*w*h)": "1280X1285X2080mm", "drilling capacity": "50mm", "spindle speed range": "115-1750/60-1350rpm", "max. milling width": "100mm", "milling diameter": "25mm", "spindle stroke": "120mm", "table size": "1000X240mm", "power(w)": "1.5/2.2kw", "product descriptions from the supplier": ">= 1 pieces", ">= 1 pieces": "$2,569", "shipping": "Shipping fee and delivery date to be negotiated. Chat with supplier now for more details.", "send inquiry": "Chat now", "hobby milling machine": "5 axis milling machine", "spindle_speed_min_rpm": 115, "spindle_speed_max_rpm": 1750}
ZX7550 | ZX7550 Mini Vertical Universal Milling Machine New DRO Drilling Milling MT4 Spindle Taper Motor Engine Manual Mills New Gear | 40 - 1400 r.p.m | 2500 | 1000 | MT4 | ZX7550-Mini-Vertical-Universal-Milling-Machine_1601453622185.html.txt | 1 Year | 30 |  |  |  | 600 | 250 | 360 | {"quantity (sets)": "1 - 1", "multispecialty supplier": "2 yrs", "voltage": "380V", "max. table load(kg)": "200", "metal working milling machine": "CNC or Not", "cnc or not": "Normal", "single package size": "140X130X208 cm", "single gross weight": "1000.000 kg", "customization options": "Chat now", "customizable": ">= 1 sets", ">= 1 sets": "$2,500", "shipping": "Shipping fee and delivery date to be negotiated. Chat with supplier now for more details.", "send inquiry": "Chat now", "hobby milling machine": "5 axis milling machine", "spindle_speed_min_rpm": 40, "spindle_speed_max_rpm": 1400}
GD800/400/550/1200/2500/3000 | Metal Milling Machine Automatic Drilling Machine GD400 800 Cnc Metal Milling Machine Making Aluminum Profile Window Door | 1000 - 24000 | 1450 | 960 | BT30/40 | Metal-Milling-Machine-Automatic-Drilling-Machine_1600519579683.html.txt | 3 years | 7 | 1800 | 800 | 1700 | 800 | 380 | 380 | {"quantity (sets)": "1 - 1", "(1 review)": "1 sold", "custom manufacturer": "4 yrs", "positioning accuracy (mm)": "Â±0.002", "repeatability (x/y/z) (mm)": "Â±0.001", "voltage": "380V,3PHASH or 220V,single phash", "number of axes": "4", "no. of spindles": "1/2/3/4/5/6/7/8", "max. table load(kg)": "2000", "dimension(l*w*h)": "1800*800*1700", "product name": "6090 Cnc Router", "spindle": "2.2kw Water Cooling Spindle", "control system": "NC-studio/Mach3", "software": "Ucancam / ArtCam/TYPE3", "type": "Advertising Cnc Router 6090", "single package size": "150X120X185 cm", "single gross weight": "800.000 KG", "customization options": "Chat now", "free shipping": "capped at $20", "capped at $20": "5-day dispatch", "customizable": "180-day lowest price", "add to cart": "Chat now", "delivery via": "Expect your order to be delivered before scheduled dates or receive a 10% delay compensation"}
ZX50C | ZX50c Mini Manual Drilling Milling Machine Metal Working Machine | 4 - 1400 r.p.m | 1099 | 600 | MT4 | ZX50c-Mini-Manual-Drilling-Milling-Machine_1601041228635.html.txt | 1 Year | 15 | 1030 | 920 | 1560 | 500 | 240 | 400 | {"quantity (sets)": "1 - 1", "no reviews yet": "1 sold", "custom manufacturer": "3 yrs", "voltage": "380V", "spindle motor power(kw)": "2.2", "dimension(l*w*h)": "1030*920*1560mm", "single package size": "30X60X60 cm", "single gross weight": "60.000 KG", "customization options": "Chat now", "free shipping": "capped at $20", "add to cart": "Chat now", "hobby milling machine": "5 axis milling machine", "spindle_speed_min_rpm": 1400, "spindle_speed_max_rpm": 1400}
ZX50C | Manual BoRui ZX50C Milling and Drilling Machine Heavy Duty Metal Bench Mill with Gear Drive for Workshop Use | 115 - 1750 r.p.m | 1950 | 550 | MT4 | Manual-BoRui-ZX50C-Milling-and-Drilling_62512870321.html.txt | 1 Year | 7 | 1100 | 970 | 1650 | 400 | 230 | 380 | {"quantity (sets)": "1 - 1", "no reviews yet": "1 sold", "brand holder": "10 yrs", "max. table load(kg)": "500", "dimension(l*w*h)": "1100X970X1650mm", "provided": "CNC or Not", "cnc or not": "Normal", "max drilling diameter": "50mm", "max boring diameter": "100mm", "spindle speed": "115-1750", "table size": "800x240mm", "spindle travel": "120mm", "single package size": "110X96X160 cm", "single gross weight": "600.000 KG", "product descriptions from the supplier": ">= 1 sets", ">= 1 sets": "$1,950", "shipping": "Shipping fee and delivery date to be negotiated. Chat with supplier now for more details.", "send inquiry": "Chat now", "chat now": "$15 off $150", "spindle_speed_min_rpm": 115, "spindle_speed_max_rpm": 1750}
ZX50C | M High-Efficiency Vertical CNc Zx50c New Condition Light Duty Metal Processing Equipment Core Motor Component Manual Mills | 40 - 1440 | 1280 | 500 | MT3 | ZX50CM-High-Efficiency-Vertical-CNC-ZX50C_1601484388276.html.txt | 1 Year | 7 | 1100 | 970 | 1650 | 400 | 230 | 390 | {"quantity (sets)": "1 - 1", "heavy duty metal processing equipment": "mt3 Spindle Taper Mill Product on Alibaba.com", "voltage": "380V, 220V, 110V", "max. table load(kg)": "300", "dimension(l*w*h)": "1100*970*1650", "shipping": "Shipping fee and delivery date to be negotiated. Chat with supplier now for more details.", "send inquiry": "Chat now"}
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

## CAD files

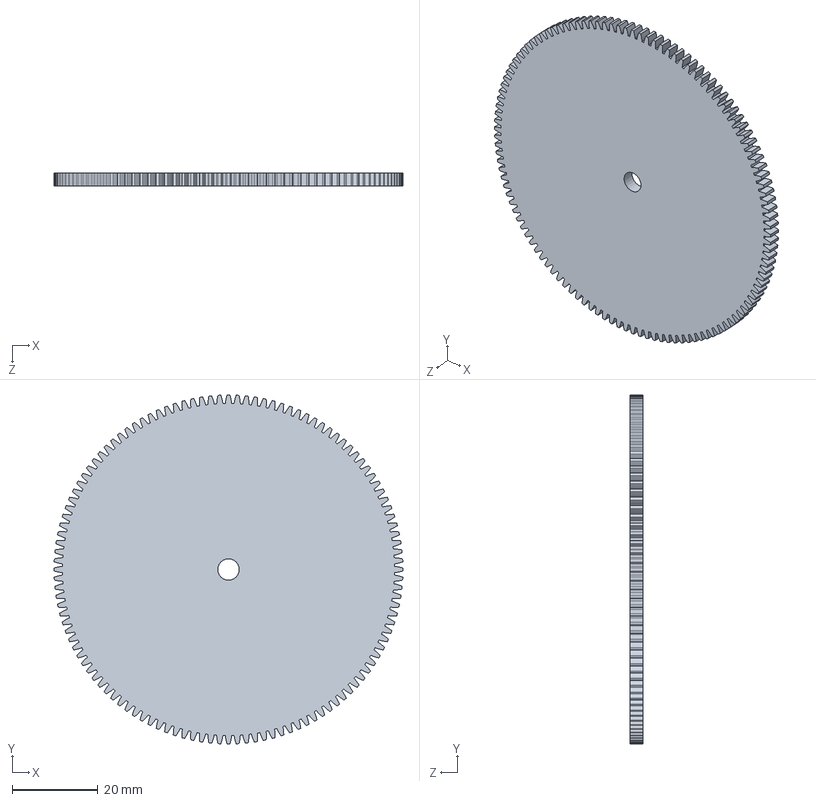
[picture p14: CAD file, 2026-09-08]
cad/docs/pipeline/evidence/vm2-datum-placement/probes/rack-fresh-source-baseline/rack-pinion.SLDPRT
81.5 x 81.5 x 3.00 mm

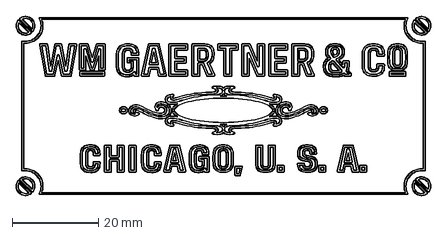
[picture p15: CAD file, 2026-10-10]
cad/references/fr-nameplate-engraving.dxf
96.2 x 41.6 mm

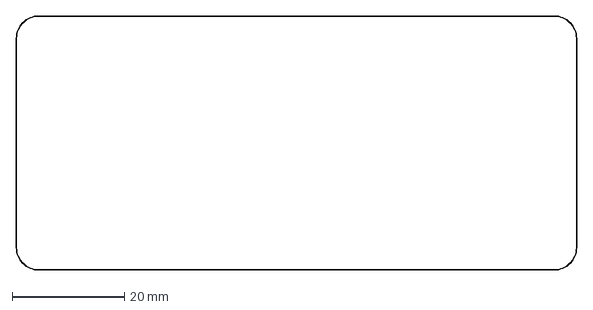
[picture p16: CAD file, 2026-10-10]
cad/references/fr-nameplate-outline.dxf
100.0 x 45.3 mm

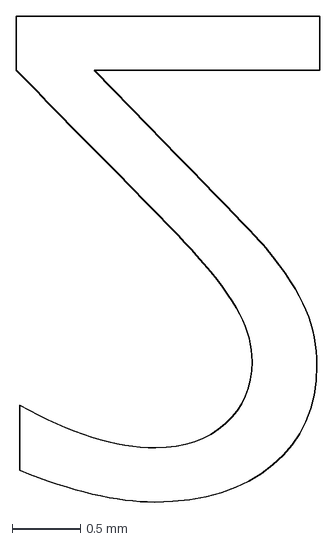
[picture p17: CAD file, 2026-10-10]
cad/references/base-serial.dxf
2.22 x 3.56 mm

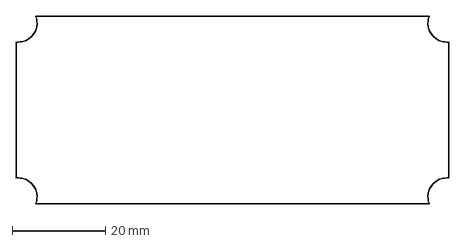
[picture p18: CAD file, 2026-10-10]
cad/references/fr-nameplate-field.dxf
92.8 x 40.2 mm

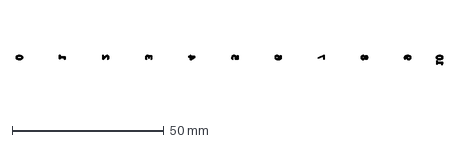
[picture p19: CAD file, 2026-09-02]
cad/references/ha-measuring-stick-numerals.dxf
140.4 x 3.01 mm

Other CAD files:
cad/docs/pipeline/evidence/vm2-datum-placement/probes/rack-post-export-source/rack-pinion.SLDPRT
cad/docs/pipeline/evidence/vm2-datum-placement/probes/rack-source-save-callout/rack-pinion.SLDPRT
cad/docs/pipeline/evidence/vm2-datum-placement/probes/rack-source-save-full/source-change-049.SLDPRT
cad/docs/pipeline/evidence/vm2-datum-placement/probes/rack-source-save-repeat/rack-pinion.SLDPRT
cad/docs/pipeline/evidence/vm2-datum-placement/probes/rack-source-save-callout/source-change-046.SLDPRT
cad/docs/pipeline/evidence/vm2-datum-placement/probes/rack-source-save-full/rack-pinion.SLDPRT
cad/docs/pipeline/evidence/vm2-datum-placement/probes/correction-f9c8bddf/production-artifacts/pinion-lift-rod.SLDDRW
cad/docs/pipeline/evidence/vm2-datum-placement/probes/correction-f9c8bddf/production-artifacts/rack-pinion.SLDDRW
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

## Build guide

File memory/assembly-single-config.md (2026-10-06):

---
name: assembly-single-config
description: "all assembly non-Default configurations (the engagement enum cone_disengaged/operating) were removed 2026-06-19 — assemblies carry only Default; PART-level multi-configs stay"
metadata:
  node_type: memory
  type: project
---

> Identity migration: narrative references may use current filenames and paths; this does not date those names to the original finding. Dated observations and metrics, historical release paths, and identifiers in quoted or captured records retain their snapshot values. See the [subsystem identity guide](../cad/docs/subsystem-identities.md) for current identities and the old-to-current map.

2026-06-19: user directive "remove all assembly non default configurations." The
drive-train and top harmonic-analyzer assemblies each carried an engagement enum
as assembly CONFIGURATIONS (`Default` / `cone_disengaged` / `operating`;
`pinion_engaged` was already retired with the alignment-pinion). All non-Default
ASSEMBLY configs are gone — every assembly now carries only `Default`.

What was removed (branch `remove-assembly-configs`):
- Deleted scripts: `build_engagement_configs.py` (cone_disengaged), `build_operating_config.py`
  (operating), `build_top_engagement_configs.py` (top child-refs), `reset_pose.py`
  (its job was snapping back from the crank-free `operating` pose).
- `_buildgraph.py`: `POST_ASSEMBLY` emptied (`{}`) — those three were the only
  post-assembly hooks; `dodo.py` docstrings de-referenced.
- `verify.py`: the whole `engagement` suite removed (`_verify_engagement`,
  `_open_isolated`, `Report.agate`, `TOP_OWNER`, the CLI `engagement` choice).
  Surviving suites: static / truth / config / isolation / motion / all. (NOTE: those
  suite names were RENAMED 2026-06-20, commit 0c39d8c1 — now soundness/kinematics/math/config;
  `isolation`→`subsystems` was later retired entirely, folded into soundness.)
- `cut_release.py`: discard-guard comments generalized (no longer cites the
  operating/pinion_engaged dirty-child case).
- `_gear_mate_names` (was imported from build_engagement_configs by
  `build_motion_setup_drives.py`) inlined into that file.

KEY distinctions:
- **PART-level multi-configs are KEPT** — cone-gear `T006..T120` (20) and
  transgear-removable `T12/T18/T24` (3) are distinct GEOMETRY the scene graph /
  release STLs reference simultaneously. Only ASSEMBLY engagement configs were the target.
- Drive-train grounding reverts to its NATIVE `fix_component` (build_harmonic_analyzer_assembly.py:99).
  The 3 principal-plane grounding mates existed ONLY to let `operating` go flexible
  at the top; with operating gone there is nothing to float, so no grounding
  conversion is needed.
- The `.SLDASM` artifacts are gitignored, so nothing committed needs regenerating;
  the next `doit` FULL build of drive_train + harmonic_analyzer produces
  single-Default assemblies. NOT YET SW-REBUILT on this seat.

Supersedes the dropped [[config-dirty-on-activate]] note (under-defined configs
dirtying the doc — moot now). Relates to [[professionalize-plan-status]] (F4
engagement suite removed), [[parametric-springs]] (its config-restore GOTCHA is
obsolete), [[od-62mm-reanchor]] (where pinion_engaged was first retired).

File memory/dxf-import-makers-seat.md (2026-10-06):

---
name: dxf-import-makers-seat
description: DXF import on the SW 3DEXPERIENCE Makers seat ignores SetPosition+SetSheetScale (bake into file); buffer line-art strokes into closed ribbons to cut
metadata:
  type: reference
---

> Identity migration: narrative references may use current filenames and paths; this does not date those names to the original finding. Dated observations and metrics, historical release paths, and identifiers in quoted or captured records retain their snapshot values. See the [subsystem identity guide](../cad/docs/subsystem-identities.md) for current identities and the old-to-current map.

Two hard, verified facts about `adapter.import_dxf_dwg`
(`IFeatureManager::InsertDwgOrDxfFile2`) on THIS SolidWorks 2026 3DEXPERIENCE
"for Makers" seat, found debugging the nameplate engraving (PR #143):

1. **The import's placement controls are NO-OPS here — bake scale AND position
   into the DXF.** `IImportDxfDwgData::SetPosition` returns `True` but never
   translates (tested mode 1 `swDwgEntitiesCentered` AND mode 2
   `swDwgEntitiesSpecifyPosition`, and reordered last). For a **flat modelspace
   DXF** `SetSheetScale` is ALSO a no-op — the artwork lands at 1:1 native mm
   regardless of the `scale`/`position` passed (rendered proof: an 88 mm target
   imported at ~280 mm, only the left third on the plate). (An earlier note that
   "SetSheetScale works" was from a blocks/INSERT DXF; it does NOT carry to flat
   modelspace.) Edition-agnostic fix: **author the DXF at FINAL plate-mm** — scale
   + centre the geometry offline so it already spans the target width on the plate
   centre, then import at `scale=1.0, position=(0,0)`. `test_fr_nameplate_geometry`'s
   golden width then equals the plate footprint (88 mm), and `build_fr_nameplate`'s
   `ENGRAVING_SCALE`→1.0 / `ENGRAVING_POSITION`→(0,0) act as swap guards.
   `GetPosition`/`GetSheetScale` getters raise "Parameter not optional" (byref
   out-params under late binding) — unrelated red herring.

2. **Traced line-art has no closed cut regions — buffer each stroke into a closed
   ribbon.** The raw engraving (46 SPLINE + 3 ELLIPSE + 8 LWPOLYLINE open strokes,
   hollow outline letters) imports and renders but cuts NOTHING —
   `create_cut_extrude`/boss both return None (no closed profile); no
   `merge_distance` (0.002–0.5 mm) helps. The 39 HATCH entities are the NEGATIVE
   field (background, letters as islands), not the ink. **Solution that shipped
   (PR #143):** offline, resolve the nested INSERTs (ezdxf `virtual_entities`,
   recurse), buffer every stroke into a thin ~0.4 mm closed ribbon and `unary_union`
   them (shapely), then scale+centre to final plate-mm and emit as ~112 closed
   modelspace LWPOLYLINEs. SolidWorks then forms regions and the cut removes real
   material (~210 mm³), reproducing the outline artwork faithfully as grooves. The
   generator is the one-off scratchpad `generate_cut_dxf.py`; git history keeps the
   original spline trace. See [[solidworks-3dx-launch]] and
   [[solidworks-modeling-pitfalls]].

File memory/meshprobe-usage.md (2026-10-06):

---
name: meshprobe-usage
description: "meshprobe (Playwright-for-3D CLI) driving notes: needs Blender >= 5.2 (auto-discovered incl. Windows as of 1.2.0), glTF must be metres, view-orbit needs --projection-json, high_key illumination for CAD inspection"
metadata:
  type: reference
---

> Identity migration: narrative references may use current filenames and paths; this does not date those names to the original finding. Dated observations and metrics, historical release paths, and identifiers in quoted or captured records retain their snapshot values. See the [subsystem identity guide](../cad/docs/subsystem-identities.md) for current identities and the old-to-current map.

meshprobe (`uv run meshprobe`, pedropaulovc/meshprobe, pinned `>=1.4.0`) inspects/renders release
GLBs in durable sessions. Hard-won usage notes (2026-07-17, filed as issues #93–#102):

- **Blender ≥ 5.2 required** (worker calls `gpu.init()`, new in 5.2; 4.5/5.1 crash with
  AttributeError). As of 1.2.0 `open` **auto-discovers Blender on Windows too** — verified
  2026-07-20 by opening a GLB with no `--blender` (EXIT 0). The old "pass
  `--blender C:/Program Files/Blender Foundation/Blender 5.2/blender.exe`" was a 0.3.0
  limitation; `--blender` now only needed to OVERRIDE the discovered install.
- **glTF units are METRES** (spec). A mm-authored GLB reads as a 457 m machine with no
  warning — author GLBs in metres.
- Coordinate mapping (in the `open` receipt): glTF +X→world +X, +Y→+Z, +Z→−Y. Machine
  coords (Y up, front = −Z) → world = (x, −z, y); front view = azimuth 90°.
- `view-orbit` REQUIRES `--projection-json`, e.g.
  `{"mode":"perspective","focal_length_mm":100,"sensor_fit":"vertical","sensor_height_mm":23.6,"sensor_width_mm":15.8}`
  reproduces the book's DX + 100 mm camera; `--target` is world-space **mm**;
  `--aspect-ratio` must match render width/height by hand.
- Renders: keep meshprobe's DEFAULT `--style screen_edges` (GPU depth/normal edge pass).
  `--style shaded_edges` is Freestyle: crisper, geometry-aware, better at separating
  same-colour adjacent parts — but CPU-bound and single-threaded, and its cost scales
  with VISIBLE COMPONENT COUNT, not resolution. Full machine at 945x2240: screen_edges
  7.3 s vs shaded_edges 31.8 s (shaded, no edges, 6.8 s). Reserve Freestyle for final
  confirmation; the GPU is used either way (receipt: `device=graphics_hardware`,
  engine eevee, `renderer` = the actual card — a slow render is NOT a CPU fallback);
  `illumination-set high_key --background-rgb 1 1 1` for SW-exported PBR metals (they
  render near-black under the default preset).
- Session state lands in `.meshprobe/` under the workspace — **gitignored** since
  PR #339 (Codex caught it committed).
- Schema discovery: `meshprobe schema --kind commands` (no per-command lookup);
  invalid preset/enum values error with the valid list — cheap discovery trick.

- **"timed out" on `open` = a Blender importer error, not a slow import (2026-09-01):**
  the v31 whole-machine `harmonic-analyzer.glb` (105 MB, 2.2 M tris) imports in ~5 s
  once it is valid; it hung for the full worker timeout because the SolidWorks glTF
  exporter wrote two primitives (`harmonic-base-1`, `top-frame-1`) whose `TEXCOORD_0`
  count differs from `POSITION`, Blender's importer raises `IndexError: index 576 is
  out of bounds`, and meshprobe 1.2.0's worker glues its error JSON onto Blender's
  un-newlined traceback line so the controller never parses the reply
  (filed upstream: pedropaulovc/meshprobe). Fixes: `export_models.sanitize_glb` now
  strips such attributes at export time (every `.glb` through `_save_as`); for an
  already-exported bundle run the same function on the file. meshprobe **1.4.0 fixes
  the worker upstream** (`emit` writes `"\n" + json + "\n"`), so a bad file now fails
  in seconds with the importer's traceback in the error (verified 2026-09-24 on a
  synthetic TEXCOORD_0-short GLB). The interim fix was a hand edit to `worker.py`
  in amet's **uv cache**, NOT the venv: uv hardlinks installs from the cache, so the
  edit reached every environment on amet and `uv sync` did NOT revert it, while farm
  workers never had it. Never patch an installed dependency in place; bump the pin.
  Bare `meshprobe find *` gets shell-expanded: quote the pattern.

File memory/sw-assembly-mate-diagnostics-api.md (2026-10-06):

---
name: sw-assembly-mate-diagnostics-api
description: How/when to fetch SolidWorks "What's Wrong", per-mate errors, and over-define/DOF info via the COM API (assembly mate debugging)
metadata:
  type: reference
---

> Identity migration: narrative references may use current filenames and paths; this does not date those names to the original finding. Dated observations and metrics, historical release paths, and identifiers in quoted or captured records retain their snapshot values. See the [subsystem identity guide](../cad/docs/subsystem-identities.md) for current identities and the old-to-current map.

When a SolidWorks assembly build hits an over-define / unsolved mate (e.g. an
`AddMate5` that returns an error, or a red-X in the tree), use these COM APIs to
get the same data the **What's Wrong** dialog and **View Mate Errors** flyout
show. Reference docs: the `developing-solidworks:developing-solidworks` skill
(`./types/`, `./enums/swFeatureError_e.md`, `learnings/detecting-broken-mates-getwhatswrong.md`).

**What's Wrong dialog →** `IModelDocExtension::GetWhatsWrong(out Features, out
ErrorCodes, out Warnings)` — three parallel arrays: feature objects, a
`swFeatureError_e` code each, and an `IsWarning` bool each. Treat `IsWarning ==
False` as a hard fault. The dialog's **Description column is NOT returned** by
this call. Key codes: `46 = mate over-defining the assembly` (usually a warning),
`47 = mate cannot be solved` (hard error), `48 = mate entities suppressed/broken`,
`2 = rebuild error`, `5/6 = sketch over/no-solution`.

**GetWhatsWrong works FINE mid-build — an earlier "it is BLIND mid-build"
entry here was WRONG and has been deleted (2026-07-25).** That verdict came
from calling it with byref VARIANTs on an early-bound extension, where the outs
ride the return tuple and the byrefs stay empty — it reported zero entries
because the data went somewhere else, not because SolidWorks had none. An A/B
against the walk proved equivalence in-build. Call it as the makepy wrapper
declares it (no args, consume the tuple) and it is live immediately, like
`IFeature::GetErrorCode2`. Cost is all TRAVERSAL: walking MateGroup's 104
subfeatures measured
5.62 s (~54 ms per `GetNextSubFeature`) vs 0.45 s for all 104 `GetErrorCode2`
reads (4.4 ms each), so scan incrementally from a remembered cursor
(`_cwm.new_mate_errors`), never per-copy from the top. Cheap per-component
signals do NOT substitute: `GetConstrainedStatus` (2–5 ms) read 4 for BOTH the
healthy seed and the broken copy, and `GetMates` counts were as expected.

**The per-mate error PROSE *is* reachable (verified 2026-07-25)** — the tree
tooltip's own wording, which is FINER-GRAINED than the code: 47's enum blurb is
the generic "This mate cannot be solved. Consider: deleting…", while the live
text distinguishes causes ("Planes are parallel but their **alignment is
reversed**. …edit this mate and change the alignment setting." vs the
dimension-flipped wording). No per-feature description API exists; instead
SolidWorks writes the prose into the SESSION MESSAGE STACK on a rebuild, and
`ISldWorks::GetErrorMessages(out Msgs, out MsgIDs, out MsgTypes)` returns it:

```python
error_messages(sw)            # DRAIN first -- the stack is read-and-clear
model.ForceRebuild3(False)    # regenerates the messages (~21 s on drive-train)
msgs = error_messages(sw)     # -> ['<Doc> - Rebuild Errors', 'Mates: …']
```

Same `[out]`-param trap as `GetWhatsWrong` (see the rule below). Traps
specific to it: the stack keeps only the last **20** messages and is cleared by
the read (drain before the rebuild or you parse stale text); **every** mate
problem arrives concatenated into ONE string with no separator
(`…red error icons.Coincident37: This mate is over…Distance32: The components…`),
so split on the mate NAMES from `GetWhatsWrong`, never on punctuation; and the
text is UI-localized while the code is not — **decide on the code, explain with
the text**. Pair it with `IMate2.Alignment` (`swMateAlign_e`: 0 ALIGNED /
1 ANTI_ALIGNED / 2 CLOSEST) + `.Flipped` / `.CanBeFlipped` to know which knob the
message is pointing at. Working script:
`cad/scripts/diagnostics/probe_mate_error_text.py`.

**The `[out]`-param trap — ONE rule: go through makepy, read the tuple.** This
bit five times in one session, so state the rule positively rather than
cataloguing victims. 542 SolidWorks methods have at least one `[out]` param
(derivable from the generated wrapper: an `_ApplyTypes_` argspec entry whose
flags have bit 2, `PARAMFLAG_FOUT`). **makepy already handles all of them
uniformly** — the generated method defaults every out to `pythoncom.Missing`
and returns them in the RETURN TUPLE:

```python
def GetWhatsWrong(self, Features=pythoncom.Missing, ErrorCodes=..., Warnings=...):
    return self._ApplyTypes_(186, 1, (11,0), ((16396,2),(16396,2),(16396,2)), ...)
```

Call with no out args, unpack the tuple — `GetWhatsWrong` → `(ok, feats, codes,
warns)`, `GetErrorMessages` → `(count, msgs, ids, types)`, `OpenDoc6` →
`(doc, errors, warnings)`, `GetErrorCode2` → `(code, is_warning)`
(`int(result)` crashes on it). Never pass byref VARIANTs to a generated
wrapper: they defeat the `Missing` defaults, stay unwritten, and `.value is
None` then reads as "no errors" — a SILENT wrong answer, which is what makes
this trap expensive.

The trap only exists where code LEAVES the makepy path, and every such place is
ours, not SolidWorks': `_common._early_bound` swallows failure and returns the
raw dispatch (`except Exception: return obj`); `sw_type_info.early_bound_or_flag`
returns the object unwrapped-but-flagged when no typed class resolves; and the
standalone probes in `cad/scripts/diagnostics/` use `GetObject`/`Dispatch`
directly, so they are dynamic and genuinely DO need byrefs — which is exactly why
a probe that works standalone can come back empty in-build. Root-cause fix
(analysed 2026-07-25, IMPLEMENTED on `fix/out-param-trap`): `_early_bound` now
RAISES instead of falling back, its `*method_names` param is gone, and
`test_out_param_binding.py` (in `recipe_tests`) bans `VT_BYREF` on the build
path and forces every late-bound diagnostic to carry a `LATE-BOUND PROBE`
marker. Do NOT write a dual-mode `call_outs()` helper — that makes the broken
mode permanent. See [[no-untested-failure-assumptions]].

**The typelib is the OFFLINE authority on any method's out-param shape.** When
you need to know what a call returns without booting SolidWorks or guessing,
read the registered type library — `pythoncom.LoadRegTypeLib(SW_TLB_IID, 34, 0, 0)`
(major 34 = SW 2026), find the interface via `GetDocumentation(i)[0]`, then
`GetFuncDesc` → `fd.rettype[0]` for the return VT and `fd.args[n][1]` for each
param's PARAMFLAG bits (1 FIN / **2 FOUT** / 8 FRETVAL); `ti.GetNames(fd.memid)`
gives `(method, *param_names)` in declaration order. makepy's return tuple is
then just `(retval, *outs_in_declaration_order)`. Worked example —
`GetErrorMessages` reads `rettype=3 (VT_I4)` with `Msgs`/`MsgIDs`/`MsgTypes` all
`vt=(26,12)` (VT_PTR→VT_VARIANT) flagged pure `FOUT`, hence
`(count, Msgs, MsgIDs, MsgTypes)` and a call taking ZERO args. Confirmed live on
the seat (`shape=tuple len=4`) — cheap enough that "typelib says X" should
always be closed out with an observation. Beats both memory and a full-build
repro: it took seconds where an assembly-level repro could not even reach the
code path.

**Not every wrong-mate state reaches the error-prose path.** Trying to
manufacture a `swFeatureError_e 47` by inverting a mate's dimension flip
(`build_ch_channel_assembly` J1a) does NOT work: the mate still SOLVES, just on the
wrong side, so the deterministic flip-seed guard raises first
(`flip-seed MISS … off by 7.06 mm, error=0`) and `_cwm.mate_error_prose` never
runs. An unsolved-mate repro needs a geometrically IMPOSSIBLE mate, not a
mirrored one.

Also `FeatureByName` is declared on `IAssemblyDoc`, not `IModelDoc2` (same
dispatch), and `IMate2` has no feature/error accessor at all — you cannot get an
error code from `IComponent2::GetMates`, only from the mate FEATURE.

**"A bare `ext.GetWhatsWrong()` raises — you must pass byrefs" was FOLKLORE,
now deleted (2026-07-25).** It holds ONLY on a late-bound dispatch (a
`GetObject`/`Dispatch` probe). Through the makepy wrapper the bare call is the
CORRECT form and the byrefs are the bug — see the `[out]`-param rule above. This
entry survived untested for months and is what sent a whole session chasing a
non-existent "GetWhatsWrong is blind mid-build" defect: a specific, confident,
un-repro'd claim is a hypothesis wearing a fact's clothes.

**Per-feature/per-mate →** `IFeature::GetErrorCode2(out IsWarning)` returns the
`swFeatureError_e` code + warning flag for ONE feature. Walk the `MateGroup`
features and call it per mate to localize the bad one.

**View Mate Errors flyout →** no dedicated API; it's `GetWhatsWrong` filtered to
mate features. The label text (`"Distance13 (crank-handle<1>, Right Plane)"`) =
`IFeature.Name`; the mated entities come from `IFeature → GetSpecificFeature2()
→ IMate2 → MateEntity(i) → IMateEntity2.ReferenceComponent/Reference`.

**DOF gotcha (gear/mechanical mates):** there is NO "remaining DOF count" API in
the bundle. `IComponent2::GetConstrainedStatus` (2=under, 3=fully, 4=over,
5=no-solution) is per-component AND is **blind to gear-mate coupling** — a
gear-coupled part reads `2` (under) even when its rotation is fully determined.
So GetConstrainedStatus cannot distinguish "1 free DOF" from an over-constrained
closed loop; you must add a probe mate and read its `AddMate5`/What's Wrong result
(an over-defining *warning* on the correct flip ⇒ that DOF is already pinned by
the mesh). Also: `AddMate5` may still CREATE the mate feature in an error/warning
state even when it returns a non-success ErrorStatus — re-`GetWhatsWrong` after.

**Bottom-dead-centre distance-driver singularity (crank driver, 2026-06-19):**
when a revolute is pinned by a single in-plane *coordinate* of an off-axis bore
(`spin_driver`: a distance from the bore to Top/Right plane), the pin is a
KINEMATIC SINGULARITY at the arm's dead-centre poses. There the two distance
solutions merge, so the constraint's Jacobian row goes rank-deficient against the
existing lock/axial mates and SW reports it as *over-defining* — even though a
genuine free spin DOF still exists (proven: a probe build that SKIPS the driver
leaves the train 1-DOF under-defined). Real case: `a45a5ea` rederived the crank
to hang straight DOWN (bottom-dead-centre), so the down-pose `spin_driver`
over-defined and drive_train hard-failed. Ground truth via `GetWhatsWrong`:
`flip=False` → the driver mate gets code **47** ("dimension flipped", hard
error); `flip=True` → code **46** over-define *warning*, co-flagging the
pre-existing `Lock2`/`Lock4` (arm/handle keyed) + `Distance1` (crank axial) as
the redundant set. So it is NOT a flip/far-side reachability issue — BOTH flips
fail, which a far-side miss never does. **Fix:** pin the spin with an `angle_driver`
instead — an angle mate's Jacobian is constant and non-degenerate at every pose,
so it pins dead-centre cleanly (the same formulation the cone-post swing-park
uses). The dihedral is read live from the arm's rest transform (`acos` of the
assembly-x component of its local +X = its Right-plane normal → 90°); `_mate`'s
flip-recovery resolves the sign and the OFFSET handle (the arm origin sits on the
spin axis) verifies the rest pose. A distance driver only works ~90° off
dead-centre (the old horizontal arm); never pin a revolute at its dead-centre
with one. See [[tube-column-od-rederive]] for that build session.

Repo already has working probes for this exact pattern:
`cad/scripts/diagnostics/probe_drivetrain_error.py` and `probe_live_drivetrain.py`
(GetWhatsWrong + GetErrorCode2), and `_add_wire1_gear` / cam-perturb in the
motion-study scripts handle pose/alignment-dependent gear over-defines.

Related: [[channel-amplitude-state]], [[build-gdi-session-accumulation]],
[[sw-recovery-dialog]], [[solidworks-modeling-pitfalls]],
[[fix-relations-last-resort]].

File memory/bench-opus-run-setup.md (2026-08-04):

---
name: bench-opus-run-setup
description: How to run cad/comparisons/bench for the Opus subject — source geometry from a release, regenerate renders, run at --effort high, push partials
metadata:
  type: project
---

Running `cad/comparisons/bench` (pose-presentation benchmark, cad/docs/pose-presentation-benchmark.md) for the **Opus** subject on a Blender-only seat (no SolidWorks / empty `cad/out`).

**Geometry from a release (no local build needed).** `render_offline.py` consumes `cad/out/{sldprt,sldasm,boxes,stl}`. Populate them from the latest release zip:
- `gh release download <tag> --pattern 'harmonic-analyzer-<tag>.zip'`
- Extract `solidworks/*.SLDPRT`→`cad/out/sldprt/`, `solidworks/*.SLDASM`→`cad/out/sldasm/`, `boxes/*`→`cad/out/boxes/`, `stl/*`→`cad/out/stl/` (zip lays them flat; render_offline wants the split dirs).
- **`touch` all of `cad/out/stl` + `cad/out/boxes` newer than the SLDPRT/SLDASM** — `_stale()` fails if `STL.mtime < SLDPRT.mtime` and the zip stores older stl mtimes.
- v0.19.0 geometry reproduces `cases.jsonl` **byte-identical** to the committed ground truth (verified) → Opus numbers are comparable to the committed codex/codex-sol columns.

**Regenerate the 270 stimuli** (out/ is gitignored, cleaned after codex): `uv run cad/comparisons/bench/gen_cases.py` (6 first-pass pairs × 45). Blender loading the ~131-STL assembly takes several minutes before the first render lands.

**"opus high" = `--effort high`.** `run_opus` in run.py hard-codes `claude -p --model opus --effort high --output-format json --permission-mode bypassPermissions`. Smoke confirms `model_id == claude-opus-4-8`. (`claude --effort` values: low/medium/high/xhigh/max.)

**Run-until-quota + periodic push** (scratchpad scripts, recreated each session — scratchpad is per-session, so they don't persist): `driver.py` re-invokes the resumable `run.py` per task (T1 n=1 → T3 n=3 → T2, `--budget-tokens 999000000` so only quota stops it) in bounded `--limit 160` passes at `--concurrency 16`, and after EVERY pass regenerates `report.py --model opus` and pushes the archive (`cad/comparisons/bench/results/opus.{results,summary,report}` — copies of `out/{results.jsonl,summary.json,report.md}`) — so ~8 min push cadence. Halts after 2 consecutive zero-progress passes (quota-exhausted; a real quota wall returns fast errors). run.py `done_keys` counts only `response!=null` as done, so rate-limit/timeout errors auto-retry next pass.

**Quota-reset timer** (`supervisor.py`): sleeps until 01:30 America/Los_Angeles (= 08:30 UTC in PDT/summer; fixed offset, no tz db) and, if cells remain and no driver is progressing (results.jsonl growth probe), launches a fresh resumable driver (→ `scratchpad/driver.next.log`); loops daily until done. Guard prevents double-running alongside a still-live driver.

**Git/PR:** PR #253 MERGED into main (first 1570 rows there + #254 COM-seat-lock refactor). Continued run went on re-pushed branch `feat/bench-opus-high` → **PR #257, MERGED 2026-07-12** at a PARTIAL stopping point: **T1 1782/1782 (complete), T3 770/1584 (~49%), T2 0/396 (not started)** — quota exhausted twice (once overnight, once at 01:55 PT after the 01:30 auto-restart). To finish T3+T2 later, re-run the driver on a fresh branch (out/ data is gitignored/local; resume works off the committed archive too). T1 total = 1782 (6 pairs × 27 subgrid tags × 11 arms × n=1); T3 = 1584 (n=3); T2 = 396. Merge was conflict-free — main advanced 81 CAD commits but none touched `cad/comparisons/bench/`.

**T3 cell_key collision fix (committed in #257, run.py `t3_key`).** The T3 cell_key keyed on delta CLASS (az/el/roll/ty/tx), but `T3_PAIRS` has 3 `az` + 2 `ty` graded-difficulty pairs sharing a class → 1584 cells collapsed to 990 unique keys. A single big pass (how codex ran) writes all 1584 rows regardless, but the resumable `--limit` driver rebuilds `todo` each pass excluding done keys, so it dropped the duplicate-class pairs → only ~990 opus rows with a DIFFERENT difficulty mix than codex (not comparable). Fixed by keying on the delta-PAIR tag (`c1.split('+',1)[1]`, e.g. `az+1`). cell_key is resume-only (never scored), so codex's recorded rows are unaffected. driver.py/supervisor.py call `R.t3_key`. If T3 ever looks like ~990 not 1584, this regressed.

**Opus-5 rerun (2026-07-24, PR #404) — what a NEW subject generation costs.**

- **A restricted tool set is mandatory, and `--allowed-tools` is NOT it.** Left
  unrestricted under `--permission-mode bypassPermissions`, claude-opus-5
  answers ~6 cells in 7 by shelling out to numpy/PIL (it will `uv venv` and
  `pip install` to get them) and computing the misregistration numerically —
  10+ min/cell vs ~30 s for a visual read, and every presentation arm collapses
  to the same pixel math, which scores a different question than the benchmark
  asks. `--allowed-tools=Read` does **nothing** here (it is a no-prompt
  allow-list, so Bash still ran — verified in the cell transcripts). The flag
  that works is **`--tools=Read --strict-mcp-config`**; the subject then reports
  Read as its only tool. Both flags are **variadic**, so pass them in `=` form —
  a separate `--tools Read` swallows the trailing prompt arg (same trap as
  codex's `-i`). `opus-5-tools` keeps the unrestricted path as a 900 s
  side-probe so the gap is measured, not assumed.
- **Read-only opus-5 cells run 20–152 s** (p50 ~50 s at concurrency 16), ~2× the
  archived opus-4.8 p50 of 25 s, so its timeout is **420 s** not 240 — the
  archived timeout would truncate the slow tail and bias the column.
- **THE CELL'S cwd WAS THE ANSWER KEY (and every archived column carries it).**
  The sandbox was named for the cell key, so a T1 cell ran in a directory
  ending `+az+3` — and Claude Code puts the working directory in prompt
  context. A probe cell quoted its own path back, read "az+3" out of it, and
  volunteered that the directory looked like an eval harness. Name sandboxes by
  the **opaque id** the stimulus files already carry (T3 keys name the
  delta-pair, T2 keys the starting perturbation — all three leaked), and keep
  the root OUT of the repo (`$TMPDIR/pose-bench-sandbox`) so a relative walk
  can't reach `cases.jsonl`. The archived `codex`/`opus` columns were collected
  before both fixes, so `run.py` refuses those subject ids without
  `--allow-archived-subject` rather than mixing harnesses under one cell key.
- **Two contamination checks worth running on any new subject**, both cheap and
  both caught real defects here: ask a cell what instruction files it sees
  (should answer NONE), and ask it to quote its cwd (should be opaque). Scan
  the cell transcripts under `~/.claude/projects/*<sandbox>*` for tool use to
  confirm what the subject actually did.
- **Comparability pin.** Regenerating stimuli on current `main` is NOT
  comparable: `cad/comparisons/manifest.json`, `tools/composite.py` and
  `render_offline.py` all drifted (camera-pose refreshes). Pin geometry to the
  **v0.19.0** release zip and `cad/comparisons/{manifest.json,tools}` +
  `bench/render_server.py` to **c8efcf1e** (last opus-4.8 bench commit), plus
  the `references` submodule to **03d58e23**. That reproduces the committed
  `cases.jsonl` to ≤3 ULP (FP noise on one pair from a different Python/Blender
  build), so keep the committed file and let the pins carry the meaning.
- The pinned `render_offline.py` hardcodes a **Windows** Blender 5.1 path with
  no env override, so a Linux seat needs a local-only
  `HARMONIC_BLENDER`/`shutil.which` patch (`main` later formalised this as
  "use any available Blender"). Unpinnable caveat: the archived columns'
  renderer version is gone from the seat (now 5.2.0 LTS) and the archived
  stimuli were gitignored + cleaned, so it cannot be pixel-verified.
- `gh release download` / `gh pr create` / `gh pr ready` all go through
  **GraphQL**, which rate-limits separately from core REST. With GraphQL at 0,
  fall back to REST: fetch the asset id from
  `repos/:o/:r/releases/tags/<tag>` then `gh api -H "Accept:
  application/octet-stream" .../releases/assets/<id>`, and POST
  `repos/:o/:r/pulls` to open the PR.
- `git checkout <sha> -- <paths>` **stages** what it restores, so a later
  `git add <other file>` + commit silently swallows the pins. Unstage them
  (`git restore --staged`) right after pinning.

See [[parallel-sw-instances-investigation]] for the COM-spine seat constraint (irrelevant here — bench needs no SolidWorks).

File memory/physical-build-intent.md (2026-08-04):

---
name: physical-build-intent
description: The model is destined for a real physical build once validated — manual mill+lathe primary, PM-30MV CNC for repetitive parts, period brass+steel
metadata:
  type: project
---

The harmonic-analyzer model is not display-only: the user (Pedro) intends to **physically machine
the entire machine** in **period brass + steel** once the model is ready and validated. This makes
DFM/DFA and the tolerance/fits work load-bearing, not academic.

Toolchain (as of 2026-07-04):
- **Primary: manual machining** — manual mill + lathe with DROs (one-off parts).
- **PM-30MV — CNC** (not manual) — available for **repetitive work**: the 20 cams, 19 spacer
  bushings, the 20-pair cone/cylinder gear train, i.e. the high-count parts where channel-to-channel
  consistency is hardest to hold by hand.
- Casting: wanted (period brass/iron blanks) but unlikely due to time.
- **CAM tool = Fusion 360** (Autodesk Makers/personal SKU, bundles CAM). External tool — so
  SOLIDWORKS CAM availability is moot. Primary feed is **STEP** (the 3D solid, already emitted by
  `SaveAs3` in `export_models.py`/`cut_release.py`) → Fusion → G-code. **STEP is the CAM feed, not
  DXF**; DXF is a narrow 2D niche (flat parts, 2.5D cam/gear-tooth profiles, inspection overlays).
  CAM cuts nominal → the toleranced 2D print (§8) carries fits/finish, not the STEP.

**Doc state (resolved 2026-07-04):** [[tolerance-gdt-assessment]] `cad/docs/tolerance-gdt-assessment.md`
§11 and `cad/docs/tolerance-policy.md` "Scope of manufacturing outputs" were revised to match this
toolchain: **CAM = IN SCOPE** (deferred until the nominal model is frozen/validated; targets the
20 cams / 19 spacers / gear train) and **DXF = IN SCOPE** as CNC 2.5D-profile input (was "optional
exhibit"). Manual mill+lathe stay primary for one-off parts. The prior "no CNC / manual-only"
assumption is corrected in-doc. The §4 "numbers don't close" Findings (fit-class vs linear-grade
mismatch, Ø6.5/6.35 pivot clearance, R800 vs 812.8 rocker radius) are the validate-before-cutting-
metal gate and must close before CAM authoring.

**How to apply:** treat tolerances/fits/surface-finish as real manufacturing outputs (see
`cad/docs/tolerance-policy.md`), not render metadata; when scoping drawings/DXF/CAM, remember CNC exists
for repeat parts. Fidelity-to-original constrains DFA part-count reduction (don't consolidate away
period brackets/screws).

**Real-build findings (2026-07-04, from `cad/docs/machining-dfm.md` "How to get this reviewed"):**
- **Automated DFM false-greens on this machine.** DFMPro (SW add-in) AND Xometry's auto-DFM both
  passed every SLDPRT — but miss the real hazards (sharp internal corners at every gear-tooth root +
  the cam notch; sub-mm walls like T006 0.49mm). Don't trust an automated-DFM green here.
- **Fusion 360 CAM verify is the primary automated check the user banks on.** It simulates the real
  tool vs the real solid, so it DOES surface sharp internal corners (as un-cut stock) + reach/gouge/
  collision — the class DFMPro misses. Blind spot: rigid geometry + held stock, so it will NOT catch
  thin-wall breakage / slender-shaft whip / tiny-part workholding (T006 0.49mm wall, Ø0.79×34mm shaft,
  1.90mm cam wall) → those need a first-article cut, not a clean sim.
- **Gear cutters for DP 49.82 don't exist commercially** (searched). Plan: **self-made form cutters
  via the Eureka method** (`references/gears-and-gear-cutting/` ch. 12), teeth cut indexed on a
  dividing head. Wire-EDM/hobbing are outsource alternates only (the shop has no 2D cutters).

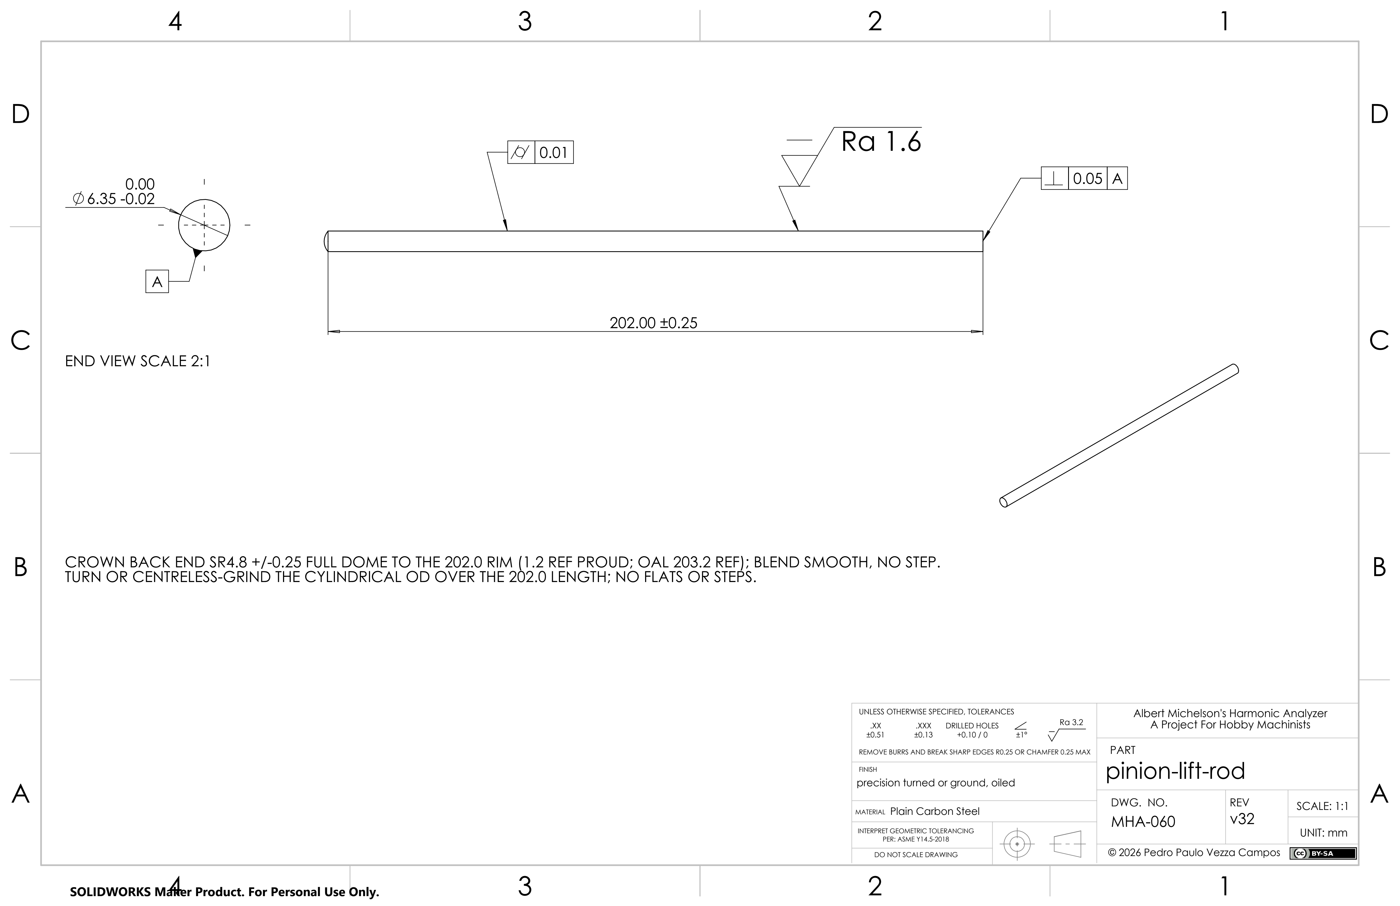
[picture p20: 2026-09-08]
cad/docs/pipeline/evidence/assembly-closeout/rod/scaled.png

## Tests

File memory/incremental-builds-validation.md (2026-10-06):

---
name: incremental-builds-validation
description: "Incremental-build validation (PR #5 refresh primitive + doit DAG, PR #9 from-empty fixes) — runtime-validated off the v0.2.0 bundle; refresh-of-unchanged reliable; the sharp edge (geometry edit dangles a mate) now AUTO-HEALS in-place via AutoMateRepair (~5s) before failing loud"
metadata: 
  node_type: memory
  type: project
  originSessionId: b8e105f4-aaf4-4af3-969f-59d752838e16
---

> Identity migration: narrative references may use current filenames and paths; this does not date those names to the original finding. Dated observations and metrics, historical release paths, and identifiers in quoted or captured records retain their snapshot values. See the [subsystem identity guide](../cad/docs/subsystem-identities.md) for current identities and the old-to-current map.

PR #5 (branch `incremental-builds-doit`, worktree `C:\src\harmonic-analyzer-doit`) adds the `refresh_assembly` primitive (reopen + per-config `ForceRebuild3` + DOF/interference/health gates + in-place `Save3`, no re-insert/re-mate) + a `doit` part→assembly DAG (`dodo.py`/`_buildgraph.py`) replacing `build_all.py`.

**Runtime-validated 2026-06-18 off the v0.2.0 release bundle** (from-scratch part build is blocked — see below — so validation ran on the already-built machine). Setup trick: `gh release download v0.2.0`, extract `solidworks/` (90 parts + 5 assemblies, Pack-and-Go flat) **flat into `cad/out/sldasm/`** so each `.SLDASM` resolves its siblings; `cad/out/sldasm` is gitignored, `cad/out/_bundle` is NOT. Build venv = `C:\src\SolidworksMCP-python\.venv\Scripts\python.exe`; needs `doit` + **`pillow`** installed and **`PYTHONUTF8=1`** (else `∩`-glyph print → cp1252 `UnicodeEncodeError`).

All 5 stages GREEN: (A) floor-cost `output` 217s vs ~500s full, in-place `Save3` **rewrites not deletes** the .SLDASM; (B) happy-path — swap a part's material, refresh, output mass shifts by **exactly** the part delta (−0.604 g) = geometry propagated without re-mating; (C) **fail-loud** — overwrite `summing-lever.SLDPRT` with `a-frame` geometry (same filename) → dangling mate → `RuntimeError: ...Coincident1 [48]`, **exit 1**, .SLDASM byte-for-byte identical; (D) top `harmonic-analyzer` full 122-comp tree clean 530.8s; (E) `drive_train` exercises the **4 configs** (`Default`+`cone_disengaged`+`operating`+`pinion_engaged`) per-config loop, clean 520.8s.

Timing insight: the **interference gate dominates** large assemblies (~390s of the top's 530s), so refresh's win is biggest on single-config subs (`output`) and shrinks on the full machine — but it always skips the fragile re-insert/re-mate. NOTE: in the v0.2.0 bundle the **engagement configs live on `drive_train`** (4 configs); the TOP `harmonic-analyzer.SLDASM` has only `Default` (refines the older dof-refactor (dropped memory) note about top-level configs).

**From-scratch build blocker → filed as issue #6** (NOT fixed, orthogonal to this PR): 3 part scripts (`amplitude_bar`/`platen`/`tube_frame`) fail at `measure_check(..., "normal_distance")` — the adapter's screen-projected `SelectByID2` (`_select_by_point`) can't pick two mutually-occluding opposite faces (they collapse to one / non-parallel), so the measure returns perimeter/area not normal_distance. Pre-existing (commit `603736f`, 2026-06-10), proven via live view-sweep on the open bar doc. Fix = view-independent measure (bbox/edge) at the 3 sites OR topology-based face selection in the adapter.

---

**Full from-scratch build pushed through → PR #9** (branch `fix-measure-opposite-faces`, worktree `C:\src\harmonic-analyzer-fixmeasure`; closes #6 + #4), 4 commits, build-infra only, NO geometry change. Surfaced + fixed FOUR latent from-empty breaks in order: (1) **#6 bbox gate** — new `_common.bbox_extent_check` unions solid `IBody2::GetBodyBox` (metres ×1000) instead of the occluding face pair; (2) **UTF-8** — `run_build` forces UTF-8 stdout so piped builds don't need `PYTHONUTF8` (replaces the cp1252 `∩` crash); (3) **#4 STL chicken-and-egg** — assembly `place_component`→`mirror_placement` reads each default-`"x"`-mirror part's `cad/out/stl/<dashed>.STL` via `stl_bbox_mm`, but only `export_models` wrote STLs and can't bootstrap from empty (manifest-driven + needs a built assembly to scan); fix = `save_part_and_images` now exports the part's fine binary mm STL via shared `_common.export_part_stl` (export_models imports the same pref ids). Parts with explicit `MIRROR_PLANE` (`"z"`/`("x",c)`/`"x0"`) skip the STL read — that's why `frame` built STL-less but `drive_train`'s `cylinder-gear-shaft` (default `"x"`) died; (4) **dead import** — `build_output_assembly.py` kept a dangling `from build_summing_lever import HOOK_HOLE_X` (+ unused `spin_driver`) the summing-lever rework removed; the mates were already migrated to the new axes, so just delete the import (probe_summing_lever uses it → `SPIN_REF_X`).

**From-empty result:** 85 parts + `frame` + `drive_train`(+3 configs) + `channel` GREEN; `output` now assembles+mates FULLY (517s, ~123 comps) but its **interference gate correctly fails → issue #8**: reworked summing-lever hex collars (`HEX_R=16`/`HEX_WIDTH=18`, low-conf) clash `knife-mount` 4549.64 mm³ + `magnifying-bracket` 18.02 mm³. KEY: the summing-lever rework (`28e5a5e`/`31d76bd`, 06-16) is IN v0.2.0's SOURCE but the bundle shipped an `output.SLDASM` built from the OLD lever → **v0.2.0 can't rebuild its own `output` from scratch**; #8 = the pending "full output-assembly re-integration" (`serialized-wobbling-lerdorf.md`), design/photo-tuning, NOT build tooling. `harmonic_analyzer` blocked behind `output`. Build_all `>>` orchestrator prints are buffered when redirected — track assemblies via subprocess activity + saved SLDASMs, not `>>` lines.

---

**doit-DAG runtime verification (PR #5's deferred Verification section) — combined branch `doit-with-fixes` (worktree `C:\src\harmonic-analyzer-doitfix`), 2026-06-18.** Per user "Create branch with 5 and 9 test there": merged `incremental-builds-doit` (PR #5) ⊕ `fix-measure-opposite-faces` (PR #9) — clean merge — so the doit DAG runs on a from-empty-buildable tree. Surfaced + fixed a **5th latent break** (validation-branch commit `79a2cdb`, since gone; the fix landed on main as `c1b1ab8` "dodo: force UTF-8 on doit parent stdout"): PR #9's Fix A only reconfigured the **subprocess** stdout, but **doit's PARENT process** re-streams each child's stdout (`doit.action._print_process_output`, a thread) and crashed on the same `∩` glyph under cp1252 when redirected — corrupting the build mid-run (3/7 frame parts silently missing, no `TaskFailed`). Fix = same utf-8/errors=replace reconfigure at `dodo.py` import top (parent-side twin of `run_build`). After it, `doit assembly:frame` builds from empty with **no `PYTHONUTF8`** (`axis pivot bore (Right Plane ∩ Plane1)` prints clean). The dodo fix belonged on PR #5 (its file) and landed on main as `c1b1ab8`.

Steps run on `frame` (uses `plane_distance_mate` = standard/named-plane refs → refresh-SAFE): **#1 floor-cost** ✅ (drive_train refresh 340s vs ~520s full, in-place Save3 rewrites). **#2 no-op** ✅ (re-run → all 7 parts + assembly `--` skipped, 0 work, no SW). **#3 happy-path** ✅ THE CORE CLAIM — bumped `corner_bracket` `LUG_HOLE_DIA` 0.4→0.42in → doit rebuilt ONLY `corner_bracket` (`.`), other 6 `--`, then `>> REFRESH frame` (NOT full), interference none + healthy + `Save3(Silent) ret=True`, **23.6s** refresh, new bracket mass propagated. **#6 config-health** ✅ (4 configs survive). **#7 structure→full** ✅ — added a comment to `build_frame_assembly.py` → all parts `--`, `>> FULL build frame (recipe changed [build_frame_assembly.py])` re-ran `create_assembly`+`insert_component` (re-insert/re-mate, bypassed refresh). **#8 dangle fail-loud** ✅ (stage C earlier). **#9 interference fail-loud** ✅ (via issue #8 output build). Probes reverted, tree clean. PR #5 + PR #9 still OPEN (no automerge per user); `doit-with-fixes` is the validation branch, not itself a PR. **REMAINING: #4 two-hop→top** (⛔ #8-gated, needs `output`+top).

**EMPIRICAL brittleness experiment (step #5, "the central unknown") — built `drive_train` (35 named-axis mates, 4 configs) + `channel` from empty via doit (3555s; doit builds `channel` as a `drive_train` dep), then ran a controlled changed-vs-unchanged refresh pair. RESULT OVERTURNS the by-inspection claim that "all-named-ref ⇒ always refresh-safe":** (Probe A) shrink `crankshaft SHAFT_DIA` 0.375→0.35in → doit rebuilds ONLY crankshaft → `>> REFRESH drive_train` → **FAULTS**: `configuration 'Default' has rebuild faults after reloading parts (dangling mate / re-IDed face?): Coincident1 [48]` → exit 1, **SLDASM byte-identical (not saved)**. `Coincident1` = the FIRST coincident = `coincident_mate(Axis1@crankshaft, Axis1@pedestal)` (axis-to-axis, both NAMED ref axes, NOT a face pick) — yet a diameter edit still dangled it (SW reports the fault on the first mate in the crankshaft solve chain). (Control 1, confounded) revert→doit chose FULL not REFRESH because Probe A's failed refresh left no success-state in `.doit.db` so the recipe read as "changed" — FULL rebuild clean. (Control 2, CLEAN ISOLATION) `refresh_assembly.py drive_train` DIRECT on the UNCHANGED 0.375 baseline → **all 4 configs "rebuilt clean", 61 components DOF-checked, interference none, healthy, `Save3 ret=True`**, exit 0. **So: refresh-of-unchanged is reliable (identical-geometry reload holds all named mates); a real geometry EDIT can dangle a mate; the gate fails loud when it does.** Brittleness is real + edit-dependent, NOT eliminated by the named-ref architecture — `frame`'s `plane_distance_mate` (pure standard planes) refreshed clean through a lug-hole edit (#3) but `drive_train`'s axis-coincident dangled on a shaft-dia edit. `world_point` is pure coord math (verified), so the "point-pick" grep count is a red herring — that does NOT make edits safe. The control run escalated to `FULL build drive_train (recipe changed [all 5 recipe .py])` — I first explained this as "the failed refresh cleared `.doit.db` state so the next run saw the recipe as changed." **That explanation is DISPROVEN** (user pushed back "files were not changed → wrong or not"): (a) toy doit success→fail→revert = `-- up-to-date` (failure does NOT discard state); (b) faithful mirror (non-deterministic part target + failed REFRESH + revert) = `changed=['part.bin'] -> REFRESH`, recipe never enters changed; (c) zero-cost replication of doit's MD5Checker on the real db = all 5 recipe files `CHANGED=False` (stable mtime); (d) `_run` just `raise`s RuntimeError, an ordinary action failure. So doit's recipe detection works correctly and the real one-off FULL is UNEXPLAINED — the pre-control db that would show it was overwritten on control's save. Did NOT invent a replacement story. DOUBLE LESSON: trust empirics over source-reading (the "all-named-ref safe" inference was wrong) AND over plausible-mechanism storytelling (the .doit.db explanation was wrong) — reproduce or say "unknown".

---

**Re-confirmed on v0.9.0 (post-#71 full-parametric self-naming parts), 2026-06-22, on the live SolidWorks seat (not a bundle).** After cutting v0.9.0 from a clean from-empty build, re-ran the controlled edit matrix on `pen`/`pen_rod` and the result is IDENTICAL to the 2026-06-18 finding — the parametric self-naming rollout did NOT change the brittleness:
- **narrative config** edit (`cad/config/dimensions.yaml`, read by no part) → `doit build_bare` = 81 `--`, 0 work. ✅ fine-grained config deps.
- **part geometry** edit (`build_pen_rod.py` `WIRE_HOLE_DIA` 2.0→2.4) → doit rebuilt ONLY `pen_rod` (cache miss), 6 other pen parts `--`, chose `>> REFRESH pen` → **FAULTS**: `refresh pen: configuration 'Default' has rebuild faults ... (dangling mate / re-IDed face?): Distance2 [48], Distance3 [48]` → exit 1, pen.SLDASM untouched. A hole-Ø edit re-IDs faces the distance mates picked. Same class as drive_train's `Coincident1` shaft-dia dangle.
- **recovery = force FULL** ✅ — `rm pen.SLDASM` → `doit assembly:pen` → `FULL build pen (target missing)` re-inserts+re-mates against the edited pen_rod, 7-comp DOF + interference clean, 33s, stored. So the fail-loud is recoverable by deleting the target (no manual mate surgery).
- **assembly-script** edit (comment in `build_pen_assembly.py`, target PRESENT) → cache miss → `FULL build pen (recipe changed)`, 73 parts `--`. ✅ recipe-change → scoped FULL.
- **ID churn CASCADES up**: after pen was FULL-rebuilt, the TOP `harmonic_analyzer` (mates to pen) went stale → its refresh ran. Here it SUCCEEDED (462.5s) because pen's LEAF parts were unchanged-geometry (only pen's own .SLDASM re-saved) — consistent with "refresh-of-unchanged reload holds all named mates". So a leaf-part edit needs FULL rebuilds cascading through every assembly that *directly* mates the re-IDed part; ancestors that only mate unchanged leaves refresh clean.

**Post-release reconciliation wrinkle — DIAGNOSED + FIXED 2026-06-22.** The first `doit` after a `release`/full build was NOT a no-op: assemblies REFRESHED once (~14 min for all 8) before settling. The earlier "late release stages re-save their referenced parts" guess was EMPIRICALLY DISPROVEN — measured a clean `frame` refresh on the live seat, hashed all 73 `.SLDPRT` before/after: **0 parts re-stamped**, only `frame.SLDASM` itself changed. cut_release/export/verify never re-save the working `.SLDPRT/.SLDASM` either (they SaveAs3 to staging/STL dirs + `CloseAllDocuments(True)`/`CloseDoc` discard). REAL root cause: `save_assembly_in_place` (the refresh save) **unconditionally** forced a fresh `.SLDASM` md5 every refresh — `SetSaveFlag` marks the clean doc dirty so `Save3` rewrites new save metadata → new bytes → new md5 "for two-hop propagation" (codex review #5). A parent's doit `file_dep` is the child `.SLDASM`'s md5, so a NO-OP refresh of a child bumped its md5 and invalidated the parent, which then refreshed + bumped ITS md5 → cascade up the tree one level per `doit` run. PROVEN zero-COM: after a no-op `frame` refresh, `assembly:harmonic_analyzer`'s recorded `frame.SLDASM` md5 (`37bb4392…`) ≠ disk (`d54ccab4…`) → top reads stale.

FIX (`cad/scripts/_assembly.py`, only file touched): added `assembly_geometry_digest()` = exact-BREP **mass-properties fingerprint** (mass/volume/COM/inertia, per config) — changes iff geometry actually changed, immune to SolidWorks' volatile save metadata AND to STL tessellation noise (15-22µm floor). `save_assembly_in_place(…, geometry_changed)` now SKIPS the save entirely when the fingerprint matches the `.<stem>.massprops.sha` sidecar (leaves `.SLDASM` byte-identical → parent stays valid → cascade dies), and force-bumps only on a real change (preserving the codex-#5 edge case where a part-change refresh leaves SW reporting the doc clean). Both the refresh path and the FULL-build path (`save_assembly_and_images`) write the sidecar, so a refresh right after a from-scratch build is a true no-op. VALIDATED on the live seat: two consecutive `frame` refreshes → 2nd logged "geometry unchanged — .SLDASM left intact (no md5 bump)", `frame.SLDASM` byte-identical; a full `build_bare` no-op-refreshed all 7 subs (each "geometry unchanged") and SKIPPED the expensive top `harmonic_analyzer` (`--`); a 3rd `build_bare` = clean no-op (all 8 `--`), `check:graph/recipe/config` green. Cost: the mass-props digest adds a per-config `get_mass_properties` pass per build/refresh — cheap on subs, ~236s on the 122-component top. **Optimization since DONE**: single-config assemblies now read mass-props in place (no redundant `activate`/`re-activate` config switches) — the digest step dropped from ~236s to **3.1s** on the top (validated on a live `frame` refresh: no `activate/re-activate` lines, no-op still detected, `.SLDASM` byte-identical). Multi-config path (drive_train's 4 configs) still switches per config (unchanged). NOTE: multi-config digest path is logically sound but not yet isolated-validated for a REAL geometry change propagating up.

---

**Sharp edge RESOLVED via AutoMateRepair auto-heal — 2026-06-22, live seat.** The dangling-mate sharp edge (a geometry edit re-IDs the face a mate selected → REFRESH dangles it → previously fail-loud, manual `rm .SLDASM` + ~500s FULL re-mate) now **auto-heals in place**. Root cause confirmed: SW mates store PID snapshots of selected topology; a from-scratch part rebuild (`create_part` → new doc) regenerates the part's PIDs, so any mate that selected its faces dangles (What's-Wrong code **48** = entity not found). **`IAssemblyDoc.AutoMateRepair(out ProcessedMates, out FailedMates)` re-binds the broken mates by re-matching the still-present (re-IDed) entities** — the exact "entities present, mate broken" case it's built for.

EMPIRICAL PROOF (non-destructive, on the live 20-channel `channel.SLDASM`): rebuilt `pivot-shaft` from scratch (PID churn, identical geometry — its OD face is selected by coordinate via `bore_axis_ref(pivot_od)` in `build_channel_assembly.py`) → reopening channel dangled all **20 J1 rocker concentrics** (code 48). `AutoMateRepair` (after selecting the Mates folder) re-bound all 20 in **~5s**; post-rebuild What's-Wrong **0 faults**; DOF (144 comps fully-defined) + interference + deep-health gates all **PASS** → geometrically valid heal, not a silent mis-bind.

WIRED INTO `refresh_assembly` (`cad/scripts/_assembly.py`), helpers `select_mates_folder` / `repair_dangling_mates` / `_rebuild_faults`: per-config loop, on a non-warning fault → `repair_dangling_mates` → `ForceRebuild3` → re-read What's-Wrong; clean ⇒ fall through to the existing DOF/interference/health gates (the safety net against mis-heal); **STILL faulted ⇒ raise** (escalate to FULL). Three GOTCHAS, each load-bearing:
1. **Judge success by What's-Wrong + gates, NOT AutoMateRepair's return code.** It returns `PartialSuccess`(1) with a large `FailedMates` array (the assembly's *already-valid* mates it "can't re-repair" — 240 of them on channel) even on a fully successful heal. Treating ret==0/Success as the criterion would always escalate.
2. **Select the Mates folder first** (a `MateGroup` feature, the documented precondition). `SelectByID2("Mates","MATEGROUP",…)` did NOT work (returned False). `FeatureByPositionReverse(0..n)` finds it in a couple of COM calls — the MateGroup is the LAST top-level feature; a forward `FirstFeature` walk costs ~50s on 144 components (validated: heal dropped 56.8s→4.4s after switching to back-scan).
3. **A heal FORCES the in-place save** (`geometry_changed = prev != digest or repaired_any`): the re-bound mate PIDs MUST persist, or a PID-churn-only rebuild (identical geometry → unchanged mass-props digest → save skipped) re-dangles + re-heals the same mates on EVERY later refresh. Composes cleanly with the cascade fix — a no-op refresh (no dangle) still skips the save, so no spurious cascade. VALIDATED twice end-to-end: dangle→heal→gates→save (`channel.SLDASM` md5 changed, healed mates persisted), 2nd run with the fast selection healed in 4.4s. Remaining unknown (contained): if a churned PID silently re-resolves to a different-but-valid face (mate NOT flagged broken → AutoMateRepair skips it), the heal is a no-op but the DOF/interference/health gates still catch the geometric error and fail loud. This SUPERSEDES the earlier "auto-escalate REFRESH→FULL on cache-miss" proposal — heal-in-place (~5s) beats escalate-to-FULL (~500s).

---

**Codex review of #83 → two P2 follow-up fixes (PR `fix-massprops-cache-and-fingerprint`, 2026-06-24).** #83 (cascade fix + AutoMateRepair) was merged by the user, then Codex posted a COMMENTED review ~47s later (the lifecycle monitor missed it — it broke on MERGED before the review landed; pull reviews/comments via `gh api repos/.../pulls/<n>/{reviews,comments}` after merge). Both P2s addressed:
1. **massprops sidecar not cached** (real cascade regression for remote-cache consumers): `_assembly_cache_outputs()` (dodo.py) restored the `.SLDASM` + renders but NOT `.<stem>.massprops.sha`, so a clean seat that PULLED an assembly hit the missing-sidecar `OSError` path on its next refresh → `geometry_changed=True` → force-saved a no-op → cascade returns. Fix: add the sidecar to `_assembly_cache_outputs` (it is machine-independent geometry-hash content, unlike the path-tagged recipe sidecar that's correctly excluded). `store()` packs only existing files, `restore()` unpacks whatever was packed → old sidecar-less entries still restore cleanly; the `_assembly.py` edit shifts every assembly cache key so all entries rebuild+republish with the sidecar.
2. **mass-props not a render-complete key**: Codex's suggested remedy (hash nested dependency files) is WRONG here and would reintroduce the cascade — a from-scratch part rebuild churns PIDs so identical geometry → different `.SLDPRT` bytes (pivot-shaft 61710→61000 B), so a content-hash key force-saves every PID-churn rebuild. Kept the geometry-derived key; added `surface_area` to `assembly_geometry_digest` (catches edits preserving mass+volume+COM+inertia). Documented the narrow residual gap: a bare part-APPEARANCE-only edit (part-level display colour, no geometry) doesn't bump the md5, so ANCESTOR renders won't auto-regen (the immediate assembly always re-exports PNGs on refresh); assembly-scope colours via `apply_component_color` go through the FULL path already, so it only bites a pure part recolour → force a rebuild to propagate. VALIDATED: two `frame` refreshes → #1 re-saves (formula changed), #2 byte-stable no-op; `check:graph`(16)+`check:cache`(11) green.

---
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

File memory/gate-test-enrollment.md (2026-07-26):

---
name: gate-test-enrollment
description: A new cad/scripts/test_*.py runs in NO gate unless enrolled in dodo.py's recipe_tests allowlist — check:recipe stays GREEN over a test nothing executes
metadata:
  type: project
---

`check:recipe` runs an **explicit allowlist**, not pytest discovery:
`recipe_tests` in `dodo.py` (~line 1714) lists files by hand plus ONE glob,
`SCRIPTS_DIR.glob("test_*_drawing.py")`. A new `cad/scripts/test_*.py` whose
name misses that glob is executed by **no gate at all** — and the gate still
reports green, so "check:recipe passed" is not evidence your new test ran.

Why this bites rather than merely annoys: the failure is invisible from where
you are working. You add a test, run `check:recipe`, see green, and conclude it
is covered. Discovered 2026-07-25 (PR #416, found by Codex, not by the build):
`test_assembly_drawing_batch_contract.py` had never been enrolled while its two
siblings `test_cone_drawing_batch_contract.py` and
`test_pen_summing_drawing_batch_contract.py` were. Reducing the channel assembly
drawing to a three-view diagram left it reading `ASSEMBLY_NOTES` /
`BOM_COMPONENTS` / `BOM_PART_NUMBERS` that the sheet no longer defined — an
`AttributeError` at import, i.e. it would have failed on collection — and every
`check:*` gate passed anyway. Enrolling it took the suite 898 → 912 tests, so
14 assertions had been dead for as long as the file existed.

**How to apply:** after adding a test file under `cad/scripts/`, confirm it is
either named `test_<stem>_drawing.py` (auto-enrolled by the glob) or added to
`recipe_tests` explicitly. Verify by the TEST COUNT moving, not by the gate
being green — run `uv run python -m doit check:recipe` before and after and
check the `N passed` number changed. Do not trust a green gate as proof of
coverage.

Related: [[no-untested-failure-assumptions]],
[[load-bearing-claims-need-repro]].

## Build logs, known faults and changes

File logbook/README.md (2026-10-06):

# Logbook: learning to machine

I am a software engineer. I designed this machine in CAD without ever having cut
metal. Before I can write a machining book, I have to become a machinist.

This directory is that process. It holds a beginner's lathe and milling course,
sized to exactly what this project needs, plus the log of actually working
through it.

The primary goal is my own competence. The book is downstream: every chapter in
[`book/`](../book/README.md) Part III gets written from the module here that
taught me the operation, and every part chapter in Part IV from the entry where
I actually cut the part. Nothing gets taught that hasn't been done.

Current Learning and Manufacture workstream status and sequencing live in the
[Harmonic Analyzer project](https://github.com/users/pedropaulovc/projects/1).
Module maturity and bench results remain in this directory.

Current part and assembly identities are listed in the
[subsystem identity guide](../cad/docs/subsystem-identities.md), including the
old-to-current lookup. Dated entries retain their original identifiers, links
and measurements; use the guide when comparing them with current CAD.

## Layout

| path | what |
|---|---|
| [`curriculum/`](curriculum/README.md) | The course. Twelve modules, M00 to M11, each ending by cutting a real part of the analyzer. |
| [`entries/`](entries/README.md) | Dated practice log. One entry per session: what I set out to do, what happened, what it cost. |
| [`SKILLS.md`](SKILLS.md) | The matrix. Skill, module, parts it unlocks, book chapter it feeds. |
| [`progress.md`](progress.md) | Derived roll-ups of hours, parts made, scrap and current technical blockers. |

## How the course is built

Every module ends by making a real part of the machine. No practice pieces for
their own sake. If a module can't be closed by cutting something the analyzer
needs, it doesn't belong in the course.

Modules are ordered by what the build needs next rather than by textbook order.
Parting off to a length tolerance comes early because thirty-eight bushings
whose lengths set the channel pitch come early.

Competency is measured, not felt. Each module has a check with a number in it,
like "hold ±0.02 mm across five consecutive parts", instead of "feel confident
turning".

The gear modules are the long pole and there is no point pretending otherwise.
Off-the-shelf cutters for this machine's diametral pitch do not exist, so M10
includes making the cutters, and it is scheduled with the most slack.

## References on hand

All in [`references/`](../references/), which is a git submodule:

- `machining-for-hobbyists-getting-started/`, the beginner spine, a chapter per topic
- `machinerys-handbook/`, the lookup, with a local search index
- `gears-and-gear-cutting/`, whose ch. 12 is the Eureka form-cutter method
- `jet-bd-920n-operators-manual.pdf`, the lathe
- `magxact-mx100m-mill-dro-manual/` and `el400-operation-manual/`, the DROs

## Machines

| | |
|---|---|
| Mill | PM-30MV (1 HP, R8, 4000 RPM) |
| Lathe | JET BD-920N (9″ × 20″) |
| Dividing head | Precision Matthews BS-0, delivered, installed and usable ([#465](https://github.com/pedropaulovc/harmonic-analyzer/issues/465)) |

## The honest note

This log records failures at full detail: scrapped parts, broken tools, wrong
speeds, misread micrometers. That is deliberate. A machining book written by
someone who has forgotten what it was like to be a beginner is a worse book, and
the mistakes are the part a reader can't get anywhere else.

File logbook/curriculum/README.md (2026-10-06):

# The curriculum

A beginner's lathe and milling course, sized to exactly what building a
Michelson harmonic analyzer requires. Nothing more, nothing decorative.

**Every module ends by cutting a real part of the machine.** If a skill can't
be closed that way, it isn't in the course.

Module maturity lives only in each linked module's `status:` frontmatter. This
index does not repeat it.

## The modules

| # | module | h `[EST]` | ends by making |
|---|---|---:|---|
| M00 | [Safety and shop setup](m00-safety-and-shop-setup.md) | 8 | — |
| M01 | [Measurement and layout](m01-measurement-and-layout.md) | 12 | — |
| M02 | [Lathe I — facing, turning, shoulders](m02-lathe-i-facing-turning-shoulders.md) | 20 | `dt-crank-pin`, `ch-pivot-shaft` blank |
| M03 | [Lathe II — drilling, boring, reaming](m03-lathe-ii-drilling-boring-reaming.md) | 16 | one `pivot-bushing` |
| M04 | [Lathe III — parting to length, batch work](m04-lathe-iii-parting-to-length-and-batch-work.md) | 20 | 19× `pivot-bushing` + 19× `lever-bushing` |
| M05 | [Lathe IV — slender work, steadies, tapers](m05-lathe-iv-slender-work-steadies-tapers.md) | 16 | `ch-pivot-shaft`, `ch-fulcrum-shaft`, `dt-cone-gear-shaft` |
| M06 | [Mill I — tramming, squaring, edge finding](m06-mill-i-tramming-squaring-edge-finding.md) | 16 | `sm-knife-mount` ×2 |
| M07 | [Mill II — profiling, slots, workholding](m07-mill-ii-profiling-slots-workholding.md) | 20 | `ch-rocker-arm` ×20, `ch-connecting-rod` ×20 |
| M08 | [Hole patterns, reaming and tapping](m08-hole-patterns-reaming-and-tapping.md) | 12 | `fr-rocker-arm-support` feet, spring-hole pattern |
| M09 | [The dividing head and indexing](m09-the-dividing-head-and-indexing.md) | 20 | `dt-cylinder-gear` alignment notches |
| M10 | [Gear cutting](m10-gear-cutting-making-the-cutter-then-the-gear.md) | 60+ | form cutters, then `dt-cone-gear` T120 → the whole train |
| M11 | [Soldering, finishing, assembly craft](m11-soldering-finishing-and-assembly-craft.md) | 16 | cone gear stack on its D-flat shaft |

Total `[EST]` ≈ **236 h**, and M10 is certainly underestimated.

## Dependency order

```
M00 ─ M01 ─┬─ M02 ─ M03 ─ M04 ─ M05 ─────────────┐
           │                                     ├─ M10 ─ M11
           └─ M06 ─ M07 ─ M09 ────────────────────┘
                 └─ M08
```

Two independent tracks (lathe and mill) that converge on gear cutting. The
lathe track is longer; start it first and slot mill modules in around it.

## Critical path

**M09 → M10.** This remains the gear-work learning sequence. The dividing head
is delivered, installed and usable, so equipment availability no longer blocks
it. M09 follows M07. M10 still requires M09 and M05, plus self-made Eureka
cutters because commercial cutters for DP 49.82 do not exist
(`cad/docs/machining-dfm.md`).

## How this feeds the book

Each module maps onto a chapter of the book's Part III, and the parts it
unlocks map onto Part IV. See [`../SKILLS.md`](../SKILLS.md) for the full
matrix. **A book chapter cannot go past `drafted` until its module is
`applied`.**

## Reading list, in order

1. `references/machining-for-hobbyists-getting-started/` — front to back, once,
   before touching anything
2. `references/jet-bd-920n-operators-manual.pdf` and the mill's manual
3. `references/machinerys-handbook/` — as a lookup, never front to back
4. `references/gears-and-gear-cutting/` — before M09, not before M10; the
   indexing chapters come first

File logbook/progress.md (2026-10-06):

# Progress

Updated as modules and entries land. Numbers come from the entries — don't
estimate here.

_Last updated: 2026-08-23 (dividing head delivered, installed and usable; no machining entries yet)._

## Modules

Module maturity lives in each linked curriculum file's `status:` frontmatter.
This table is only the entry-derived hours roll-up.

| # | module | h est | h actual | entries |
|---|---|---:|---:|---:|
| M00 | [Safety and shop setup](curriculum/m00-safety-and-shop-setup.md) | 8 | 0 | 0 |
| M01 | [Measurement and layout](curriculum/m01-measurement-and-layout.md) | 12 | 0 | 0 |
| M02 | [Lathe I — facing, turning, shoulders](curriculum/m02-lathe-i-facing-turning-shoulders.md) | 20 | 0 | 0 |
| M03 | [Lathe II — drilling, boring, reaming](curriculum/m03-lathe-ii-drilling-boring-reaming.md) | 16 | 0 | 0 |
| M04 | [Lathe III — parting to length](curriculum/m04-lathe-iii-parting-to-length-and-batch-work.md) | 20 | 0 | 0 |
| M05 | [Lathe IV — slender work](curriculum/m05-lathe-iv-slender-work-steadies-tapers.md) | 16 | 0 | 0 |
| M06 | [Mill I — tramming, squaring](curriculum/m06-mill-i-tramming-squaring-edge-finding.md) | 16 | 0 | 0 |
| M07 | [Mill II — profiling, workholding](curriculum/m07-mill-ii-profiling-slots-workholding.md) | 20 | 0 | 0 |
| M08 | [Hole patterns and tapping](curriculum/m08-hole-patterns-reaming-and-tapping.md) | 12 | 0 | 0 |
| M09 | [Dividing head and indexing](curriculum/m09-the-dividing-head-and-indexing.md) | 20 | 0 | 0 |
| M10 | [Gear cutting](curriculum/m10-gear-cutting-making-the-cutter-then-the-gear.md) | 60+ | 0 | 0 |
| M11 | [Soldering and finishing](curriculum/m11-soldering-finishing-and-assembly-craft.md) | 16 | 0 | 0 |
| | **total** | **236+** | **0** | **0** |

## Parts made

| part | qty needed | qty made | qty scrapped | first entry |
|---|---:|---:|---:|---|
| — | | | | |

`0 / 146` registered part families started. The inventory and identity lookup
are documented in the [subsystem identity guide](../cad/docs/subsystem-identities.md);
bench progress comes from the entries above.

## Blocked on

| # | blocker | blocks | action |
|---|---|---|---|
| 1 | Gear-cutter blanks + tool steel not sourced | M10 | Source gear-cutter blanks and tool steel. |
| 2 | `sm-summing-lever` body and knife-edge methods undecided | ch. 27; no module assigned yet | Decide cast / fabricate / hog and integral / insert before buying stock. |
| 3 | Spring specification not written | ch. 31 | Rate matching across 20 channels is a spec problem first. |

## Rhythm

The book's credibility and the campaign's both depend on this log updating
visibly and regularly. One entry per session, published as it happens.

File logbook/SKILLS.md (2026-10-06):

# Skills matrix

The join table between the three deliverables that depend on each other:
**a curriculum module teaches a skill → the skill unlocks parts → the parts and
the skill become book chapters.**

Rule: **a book chapter may not go past `drafted` until its module is
`applied`.** Prose about an operation that hasn't been performed is the one
failure mode that would make the book worthless.

| skill | module | parts it unlocks | book chapter |
|---|---|---|---|
| Shop safety, machine setup | M00 | — | `front/safety.qmd` |
| Measurement, layout, reading GD&T | M01 | — | ch. 6 Measuring |
| Facing, turning to diameter, shoulders | M02 | `dt-crank-pin`, `dt-crankshaft`, `dt-crank-handle`, `mg-wheel-axle`, screw blanks | ch. 9 Turning |
| Drilling, boring, reaming to a fit | M03 | `pivot-bushing`, `lever-bushing`, `dt-cylinder-gear` bore, `sm-knife-mount` bore, `mg-magnifying-wheel` | ch. 10 Drilling, boring, reaming |
| Parting to a length, batch repeatability | M04 | 19× `pivot-bushing`, 19× `lever-bushing`, spacers | ch. 11 Parting to a length tolerance |
| Slender turning, steadies, followers | M05 | `ch-pivot-shaft`, `ch-fulcrum-shaft`, `dt-cone-gear-shaft`, `dt-cylinder-gear-shaft`, `dt-pinion-arbor`, `ch-amplitude-bar` | ch. 12 Slender work |
| Tramming, squaring, edge finding | M06 | `sm-knife-mount` ×2, `dt-pinion-pivot-block`, `pd-transgear-arm`, `dt-arbor-pedestal` | ch. 13 Milling |
| Profile milling, slots, batch fixturing | M07 | `ch-rocker-arm` ×20, `ch-connecting-rod` ×20, `ch-channel-lever` ×20, `pd-platen-guide`, `mg-wheel-bar` | ch. 13 Milling |
| Hole patterns, reaming, tapping | M08 | `fr-rocker-arm-support` (4× 1/2-13 UNC-2B, `cad/scripts/build_fr_rocker_arm_support.py`), `sm-summing-lever` 20× Ø2.0 pattern, `fr-harmonic-base` | ch. 14 Hole patterns and tapping |
| Dividing head, indexing, co-phasing | M09 | `dt-cylinder-gear` notches ×20, every gear blank | ch. 15 Indexing |
| Form-cutter generation (Eureka) | M10 | the cutters themselves — **nothing in the gear train without them** | ch. 16 Making your own gear cutters |
| Gear cutting and inspection | M10 | `dt-cone-gear` ×20, `dt-cylinder-gear` ×20, `dt-crank-pinion`, `dt-alignment-pinion`, `pd-rack-pinion`, `pd-transgear-*`, `vn-transgear-*`, `pd-chain-sprocket`, `pd-platen-rack` | ch. 17 Cutting the gears |
| D-bore fitting, gear-stack assembly | M11 | 64T + cone gear set → D-flat shaft | ch. 18 Fitting D-bores and the cone gear stack |
| Silver soldering | M11 | `dt-crank-pin-ring` ends | — |
| Draw filing, polishing, blacking | M11 | every visible part | ch. 19 Finishing |
| Assembly, alignment, calibration | — (learned on the machine) | the whole analyzer | ch. 33–35 |

## Parts with no module yet

These need a decision before a module can be written for them:

| part | question |
|---|---|
| `sm-summing-lever` | Cast, fabricate, or hog from solid? Each answer is a different skill. `cad/docs/machining-dfm.md` recommends not hogging. |
| `sm-summing-lever` knife edge | Machine into the parent, or make a hardened tool-steel insert? |
| `fr-rocker-arm-support`, `ch-connecting-rod` | Cast or cut from bar? (Both benign as bar.) |
| `vn-counter-spring`, `vn-channel-spring-installed` ×20 | Wind your own (a module) or specify to a spring house (a procurement task)? |
| `vn-chain-inner-link` / `vn-chain-outer-link` / `pd-chain-sprocket` | Make the roller chain or buy it? |
| `ha-measuring-stick` | Hand stamping — a small module of its own, or a paragraph? |

## Coverage check

Run this occasionally: does every Tier-1 part in `cad/docs/machining-dfm.md` appear
in the "parts it unlocks" column above? A T1 part with no module is a hole in
the curriculum, and it will become a hole in the book.

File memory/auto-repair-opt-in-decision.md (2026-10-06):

---
name: auto-repair-opt-in-decision
description: Decision to NOT silently auto-heal cache-restored dangling mates — offer an opt-in --auto-repair retry instead (tracked in issue #204)
metadata:
  type: project
---

> Identity migration: narrative references may use current filenames and paths; this does not date those names to the original finding. Dated observations and metrics, historical release paths, and identifiers in quoted or captured records retain their snapshot values. See the [subsystem identity guide](../cad/docs/subsystem-identities.md) for current identities and the old-to-current map.

When a remote-cache **partial-mix dangle** fails `verify:soundness`
(`[48]` dangling mates on a foreign cached `.SLDASM`), the remedy today is the
slow `HARMONIC_REMOTE_CACHE_MODE=off` FULL rebuild (~500 s/assembly) — see
[[cache-partial-mix-dangle-remedy]]. The `AutoMateRepair` primitive that would
heal it in ~5 s already exists (`repair_dangling_mates` @ `_assembly.py:2103`,
called only from `refresh_assembly` @ 2261) but never fires on a cache HIT
(never marked stale — the `dodo.py:940-959` KNOWN LIMITATION).

**Decision (Pedro, 2026-07-08, cutting v0.17.0):** do NOT wire a silent
auto-heal. Keep the loud failure as default; expose an **opt-in `--auto-repair`**
flag on `verify.py --suite soundness`, so the operator consciously weighs
AutoMateRepair's risk (it can re-bind a mate to the WRONG topology →
subtly-wrong shipped geometry) against the ~500 s→~5 s gain, case by case.

**Implemented for issue #204:** only non-warning
What's Wrong code 48 is eligible. The repair is rebuilt and re-read, then the
normal DOF / over-constraint / deep-health / interference / channel-independence
battery runs. The `.SLDASM` is saved locally only if every gate passes; it is not
republished under the foreign remote-cache key. Default soundness still fails
loud and includes the exact opt-in retry command.

**How to apply:** retry one affected assembly with, for example,
`uv run python cad/scripts/verify.py ch_channel --suite soundness --auto-repair`.
Never turn this into an unconditional verify/cache heal.

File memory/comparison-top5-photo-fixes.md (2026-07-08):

---
name: comparison-top5-photo-fixes
description: "2026-07-08 gallery vision pass: top-5 model-vs-photo fixes (green resample, paper z-fight, painted summing lever/wheel/pen) + the traps found on the way"
metadata:
  type: project
---

2026-07-08 vision pass over all 18 regenerated comparison pairs (PR #209,
branch `photo-match-top5`). The five fixes and the reusable lessons:

1. **`casting_green` was pastel teal.** The palette claimed "sampled from the
   ch30 plates" but carried R=0.13; median patch-sampling the actual plates
   (ch30 p002/p009 frame+base, ch17/ch18 lever) gives R≈0.05·G, B≈0.85·G →
   `(0.03, 0.45, 0.38)`. **How to apply:** when a palette entry claims
   "photo-sampled", re-derive it with PIL median patches before trusting it.
2. **Coplanar faces z-fight in the offline renders.** The platen paper's back
   face landed exactly on the platen front face → every ch30 front view drew
   the paper as torn black/white triangle shards (worse at far/ortho zoom,
   clean in close-ups, so it looks like a "corrupt mesh" but isn't).
   **How to apply:** keep the repo's 0.25 margin rule for FACE-ON-FACE decals
   too (paper, plates, labels) — a 0.25 air gap behind the decal kills it;
   verify by re-render, not by interference gates (0-volume contact passes
   them). See [[solidworks-modeling-pitfalls]].
3. **Summing lever + pen v-block are green-painted, magnifying wheel is
   black-painted** (ch17/ch18/ch24/p.51). Parts relying on bare
   `apply_material` appearance (Gray Cast Iron / Brass) read wrong in the
   gallery; the painted machine parts need explicit `apply_color`.
   `materials.yaml casting_green_parts` is the (doc-only) list — keep it in
   sync.
4. **Pen marker**: blunt 5 mm nose + nickel colour (was 12 mm needle cone,
   brass). Still VERTICAL — the tilt/paper-contact stays a documented
   Appendix C simplification; a real fix means angled v-block bores and a
   pen-frame window rework.
5. **Wheel "8 spokes" was a miscount.** The magnifying wheel HAS 6 spokes
   (verified by point-in-solid parity probing of the STL at r=25..38); the
   wheel-bar + column behind it read as 2 extra spokes in renders. **How to
   apply:** before "fixing" a pattern count seen in a render, probe the STL —
   vertex-angle histograms DON'T work (box spokes have no mid-span vertices).

**Trap: `_common.py` is in every part's recipe digest.** Editing the palette
constants there invalidates the whole fleet (~100 parts) → full rebuild. If
palette tweaks become frequent, move the palette source of truth into
`cad/config/materials.yaml` behind a `_config` accessor (+ `_buildgraph`
mapping) so a colour edit rebuilds only the parts that read it.

Remaining known visual deltas (NOT fixed, next candidates): crank handle is
black with a brass ferrule in ch11 (model: plain dark-oak teardrop);
connecting rods read near-black in plates vs 0.267 gray; nameplate sits flat
on the base deck vs the plinth front bevel in ch26 (+ an unidentified silver
gear rendered on the deck near it — investigate `transgear-removable` spares);
wheel-axle's 35 mm silver flange reads bigger/brighter than the photo hub;
summing lever webbed-casting shape ([[summing-lever-true-geometry]]).

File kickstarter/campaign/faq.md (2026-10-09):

# FAQ

Drafts. Rewrite in campaign voice before publishing; keep the answers this
blunt.

**Is this the same as the engineerguy book?**
No. Hammack, Kranz and Carpenter's *Albert Michelson's Harmonic Analyzer*
(2014) is a beautiful visual tour of the machine — it shows you what it is.
This book tells you how to make one. It is an independent project, not
affiliated with or endorsed by them, and it cites their work throughout. Go
read theirs; it's free.

**What happens to the machine you build?**
It goes to [Matemateca](https://matemateca.ime.usp.br/index_ingles.html), the
mathematics outreach collection at the University of São Paulo's Institute of
Mathematics and Statistics. They use objects to teach mathematics to the public
and to school groups, and this one will be used with middle and high schoolers.
I don't keep it. That is also why the build targets a machine that survives
being operated by teenagers rather than one that looks good in a photograph.

**Can I buy a finished machine, or a kit?**
No. Building one analyzer is this project. Building them to order is a
different business, and pretending otherwise is how campaigns fail.

**Do I need CNC?**
No. The book is written for a manual mill and lathe, which is what the original
maker had. Six part families repeat 19–20 times and CNC makes those less
tedious — the book notes where, but never requires it.

**What machines and tooling do I actually need?**
A bench mill, a lathe, a dividing head, and a normal measuring kit. The full
list with sizes is in the book's shop-setup chapter, and it is published free
before launch so you can decide before you pledge.

**How hard is this really?**
Hard. One part — a six-tooth gear about 4 mm across with a 0.49 mm wall at the
tooth root — is genuinely at the edge of home-shop capability, and off-the-shelf
cutters for the gear train's pitch do not exist, so you make your own. The book
says exactly where the difficulty is instead of pretending it's uniform.

**How long does a build take?**
Unknown, honestly. The CAD inventory has
[149 registered part families](../../cad/docs/subsystem-identities.md), including
parts repeated across the twenty channels.
The logbook records real hours per part as they are cut, and the book publishes
those numbers.

**Do I have to build the whole thing?**
No, and the book is structured so you don't have to. The cone gear set alone is
a satisfying, self-contained project; so is a single channel.

**Are the CAD files free?**
Yes. The model, the STEP exports and the drawing sheets are MIT-licensed and
already public on GitHub, funded or not. You are paying for the book — the
process, the setups, the tolerances, the failures.

**What if the machine doesn't work?**
Then the book documents why, and that's still the book. The machining chapters
stand on their own, and a failed calibration analyzed properly is more useful
than a success story with the details left out.

**Why are you qualified? You said you're learning.**
I'm not a machinist — I'm a software engineer who did the engineering design
work and is learning to machine it. That's exactly who the book is for. Every
mistake I make gets written down while it's still fresh, which is not something
an expert can do.

**Where does the money go?**
Stock, tooling, spring winding, editing, layout, photography, printing and
shipping. The breakdown is published in the repo. The mill, the lathe and the
CAD work are already paid for and are not in the goal.

**When do I get it?**
See the timeline on the campaign page. The digital edition ships first.

**Shipping outside the US/EU/BR?**
TBD before launch — see `../rewards/fulfilment.md`.

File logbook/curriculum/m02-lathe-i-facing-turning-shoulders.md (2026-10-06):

---
module: M02
title: "Lathe I — facing, turning, shoulders"
status: not started      # not started | in progress | competent | applied
hours_estimated: 20
hours_actual: 0
---

# M02 — Lathe I — facing, turning, shoulders

## Objectives

- Face a bar square
- Turn to a diameter and hit it
- Cut a shoulder to a length
- Get a finish you would put in a book

## Prerequisites

- m01

## References

- `references/machining-for-hobbyists-getting-started/07_chapter-5-introduction-to-lathes.pdf`
- `references/machining-for-hobbyists-getting-started/08_chapter-6-working-on-lathe.pdf`
- `references/machinerys-handbook/` (speeds and feeds)

## Practice

- Tool grinding or insert selection; centre height
- Roughing vs finishing: why the last 0.05 mm behaves differently
- Speeds and feeds for brass and mild steel at 5-25 mm diameters
- Chatter: recognising it and the four things that cause it
- Taper: diagnosing headstock alignment vs tool deflection

## Now make — the real part this unlocks

**`dt-crank-pin`** and a **`ch-pivot-shaft`** blank — plain turned steel, no bore, no step. The first real parts of the analyzer.

## Competency check

Five consecutive parts turned to a nominal diameter within ±0.02 mm, with a finish that needs no filing.

## Notes

Brass and steel behave completely differently. Do both from the start — this machine is mostly brass, and brass punishes a tool with positive rake.

## Sessions

Log entries for this module, newest last. Create them with
`entries/TEMPLATE.md`; **an agent may create the file, only you may fill it in.**

| date | entry | outcome | hours |
|---|---|---|---|
| | | | |

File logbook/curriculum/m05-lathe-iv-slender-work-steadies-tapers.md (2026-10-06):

---
module: M05
title: "Lathe IV — slender work, steadies, tapers"
status: not started      # not started | in progress | competent | applied
hours_estimated: 16
hours_actual: 0
---

# M05 — Lathe IV — slender work, steadies, tapers

## Objectives

- Turn long slender work without whip
- Set up and use a fixed steady and a follower
- Cut a taper

## Prerequisites

- m04

## References

- `references/machining-for-hobbyists-getting-started/08_chapter-6-working-on-lathe.pdf`
- `cad/docs/machining-dfm.md` (`dt-cone-gear-shaft`, `ch-pivot-shaft`, `ch-fulcrum-shaft`)

## Practice

- Between centres: setting up, driving, and why it beats a chuck here
- The fixed steady: where to put it, how to set it without bending the work
- The travelling steady
- Depth of cut and feed on slender work; the finishing pass
- Tapers: tailstock offset, taper attachment, compound

## Now make — the real part this unlocks

**`ch-pivot-shaft`** (Ø6.35 × 203.2, L/D 32:1) and **`ch-fulcrum-shaft`** (Ø6.35 × 182, 29:1). Then, when M02-M05 are all solid, the **`dt-cone-gear-shaft`** — five steps ending in a Ø0.79 × 34 mm journal in steel, 43:1.

## Competency check

A 30:1 shaft turned parallel within 0.02 mm over its length.

## Notes

The cone-gear-shaft tip is one of the three riskiest features in the machine. Do not attempt it until the 30:1 shafts are routine.

## Sessions

Log entries for this module, newest last. Create them with
`entries/TEMPLATE.md`; **an agent may create the file, only you may fill it in.**

| date | entry | outcome | hours |
|---|---|---|---|
| | | | |

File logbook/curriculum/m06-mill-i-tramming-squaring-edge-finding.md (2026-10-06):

---
module: M06
title: "Mill I — tramming, squaring, edge finding"
status: not started      # not started | in progress | competent | applied
hours_estimated: 16
hours_actual: 0
---

# M06 — Mill I — tramming, squaring, edge finding

## Objectives

- Tram the head and know when it has drifted
- Square a block on all six faces
- Find an edge and trust the DRO after it

## Prerequisites

- m01

## References

- `references/machining-for-hobbyists-getting-started/09_chapter-7-milling-machines.pdf`
- `references/magxact-mx100m-mill-dro-manual/`

## Practice

- Tramming: the sweep method, and how often to re-check
- Vice alignment and the parallels that ruin it
- Squaring a block: the order of faces
- Edge finding: mechanical, electronic, and the tool-diameter arithmetic
- Climb vs conventional on a machine with backlash

## Now make — the real part this unlocks

**`sm-knife-mount`** ×2 — a rectangular block 34 × 43.77 × 14, the simplest prismatic part in the machine, and there are two of them.

## Competency check

A block square within 0.02 mm across 40 mm, verified on a surface plate.

## Notes

Watch the 4 mm floor under the knife-mount's Ø25.4 bore when you get to boring it — breakout there scraps the part.

## Sessions

Log entries for this module, newest last. Create them with
`entries/TEMPLATE.md`; **an agent may create the file, only you may fill it in.**

| date | entry | outcome | hours |
|---|---|---|---|
| | | | |

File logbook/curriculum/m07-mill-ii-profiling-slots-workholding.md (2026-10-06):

---
module: M07
title: "Mill II — profiling, slots, workholding"
status: not started      # not started | in progress | competent | applied
hours_estimated: 20
hours_actual: 0
---

# M07 — Mill II — profiling, slots, workholding

## Objectives

- Mill a 2D profile to a line
- Cut a slot to width
- Hold twenty identical parts identically

## Prerequisites

- m06

## References

- `references/machining-for-hobbyists-getting-started/09_chapter-7-milling-machines.pdf`
- `cad/docs/machining-dfm.md` (`ch-rocker-arm`, `ch-connecting-rod` rows)
- `cad/scripts/build_ch_rocker_arm.py`

## Practice

- Profile milling: cutter comp by hand, leaving a finishing pass
- Arcs on a manual machine: rotary table, template, or file-to-line
- Slots: width, and why a slot is never the cutter diameter
- Simple fixtures, stops, and soft jaws
- Twenty identical profiles without CNC

## Now make — the real part this unlocks

**`ch-rocker-arm`** ×20 (2.5 mm steel, R800 concave top edge — the **outline** of the plate, not a pocket) and **`ch-connecting-rod`** ×20 (flat 2D profile, book-accurate rough finish).

## Competency check

Twenty rocker arms whose pivot-to-pin distance varies by less than 0.05 mm across the set.

## Notes

The R800 arc is what the amplitude bar rides on. Its consistency across twenty parts is a functional requirement, not cosmetic.

## Sessions

Log entries for this module, newest last. Create them with
`entries/TEMPLATE.md`; **an agent may create the file, only you may fill it in.**

| date | entry | outcome | hours |
|---|---|---|---|
| | | | |

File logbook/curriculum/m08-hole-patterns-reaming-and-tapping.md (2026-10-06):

---
module: M08
title: "Hole patterns, reaming and tapping"
status: not started      # not started | in progress | competent | applied
hours_estimated: 12
hours_actual: 0
---

# M08 — Hole patterns, reaming and tapping

## Objectives

- Drill a pattern to position
- Tap a hole without breaking the tap
- Ream in the mill

## Prerequisites

- m06

## References

- `references/machinerys-handbook/` (tap drill sizes, thread data)
- `cad/docs/machining-dfm.md` (`fr-rocker-arm-support`, `sm-summing-lever`)
- `cad/scripts/build_fr_rocker_arm_support.py` (foot thickness, four-hole pattern and 1/2-13 UNC-2B thread)
- `cad/scripts/_holes.py` (`TAP_DRILL_MM["1/2-13"]`)

## Practice

- Position tolerance and what it means when you drill
- Spot drill, drill, ream — and when to skip a step
- Tapping by hand, under the spindle, and with a tapping head
- Blind holes: tap drill depth, bottoming taps, chip packing
- Breakout on a thin floor

## Now make — the real part this unlocks

**`fr-rocker-arm-support`** foot holes: 4× 1/2-13 UNC-2B through the 6.35 mm foot, tap drill Ø10.716 mm (Ø10.72 displayed; 27/64 in), from `cad/scripts/build_fr_rocker_arm_support.py` and `cad/scripts/_holes.py`. Then the 20× Ø2.0 spring holes in the summing lever at 7.0565 mm pitch.

## Competency check

A four-hole pattern within 0.1 mm true position, and a 1/2-13 UNC-2B thread cut clean without a broken tap (the support thread specified in `cad/scripts/build_fr_rocker_arm_support.py`).

## Notes

The support feet are one tapped joint among several; the knife-mount hanger-stud seat is another (`cad/docs/machining-dfm.md`). There are no keyways: gears seat on D-flats, are pinned, or run free on an arbor.

## Sessions

Log entries for this module, newest last. Create them with
`entries/TEMPLATE.md`; **an agent may create the file, only you may fill it in.**

| date | entry | outcome | hours |
|---|---|---|---|
| | | | |

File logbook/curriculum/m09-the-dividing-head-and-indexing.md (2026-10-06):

---
module: M09
title: "The dividing head and indexing"
status: not started      # not started | in progress | competent | applied
hours_estimated: 20
hours_actual: 0
---

# M09 — The dividing head and indexing

## Objectives

- Set up a dividing head and trust it
- Index simple divisions from 6 to 120
- Return to a datum and co-phase multiple parts

## Prerequisites

- m07

## References

- `references/gears-and-gear-cutting/gears-and-gear-cutting.pdf`
- `references/machinerys-handbook/` (indexing tables)
- `cad/scripts/build_dt_cylinder_gear.py` (the +Y notch datum)

## Practice

- How a dividing head works; ratio, plates, sector arms
- Simple indexing for every division this machine needs: 6, 12, 18 ... 120
- Setting a datum you can return to tomorrow
- Backlash in the index: always approach from one direction
- Co-phasing: making twenty parts share one angular reference

## Now make — the real part this unlocks

The **0.4 mm alignment notch** on the `dt-cylinder-gear`s — then prove you can repeat the phase on a second part.

## Competency check

Two parts, cut on different days, whose notches are within 0.5° of the same angular datum.

## Notes

The dividing head is delivered, installed and usable. Equipment availability is
not competency; module maturity is recorded only in the `status:` frontmatter.
The 0.4 mm slitting saw for the notch will grab if the feed stalls.

## Sessions

Log entries for this module, newest last. Create them with
`entries/TEMPLATE.md`; **an agent may create the file, only you may fill it in.**

| date | entry | outcome | hours |
|---|---|---|---|
| | | | |

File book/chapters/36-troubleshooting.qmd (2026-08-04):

---
title: "When it doesn't work"
status: stub
---

# When it doesn't work {#sec-troubleshooting}

Symptom, cause, fix. Written from the real calibration — every entry here happened.

::: {.callout-note appearance="simple"}
**TODO** — stub. Nothing here has been written yet.
:::

## The pen does not move

TODO

## The output is flat when it should not be

TODO

## One channel contributes nothing

TODO

## The trace drifts across the paper

TODO

## The trace is noisy or stepped

TODO

## The crank binds at one point in the rotation

TODO

## The wheel unwinds and the wires fly off

TODO

## The output is right but the amplitude is wrong

TODO

---

**Sources for this chapter**

- `logbook/entries/`

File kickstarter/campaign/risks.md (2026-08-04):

# Risks and challenges

Kickstarter requires this section. Written straight — the people who read it
carefully are the ones who back at the top tiers.

## Technical

**The six-tooth cone gear may not be machinable in my shop.** It is a ~4.08 mm
outside diameter gear on a 0.79 mm bore, leaving a 0.49 mm wall at the tooth
root. `cad/docs/machining-dfm.md` calls it the single hardest part in the machine.
*Mitigation:* the original used a harder yellow metal for the tip gears; if my
first articles fail, the book documents the failure and the fallback (outsourced
wire-EDM), which is itself useful to a reader. **The book ships either way.**

**Off-the-shelf gear cutters for DP 49.82 do not exist.** Confirmed after an
exhaustive search. The plan is to generate form cutters by the Eureka method
(*Gears and Gear Cutting*, ch. 12). This is a documented technique, but it is a
skill I do not yet have. *Mitigation:* it is scheduled early in the learning
curriculum precisely because it is the long pole.

**The summing lever's knife edge is a casting-shaped organic part with a
delicate precision ridge.** Current thinking is a hardened tool-steel insert
rather than machining it into the parent. Unresolved.

**The model may be wrong somewhere.** Every dimension is traced to a source with
a confidence level, but the surviving machine has not been measured directly —
the model is derived from photographs, the 1898 paper, and the 2014 book.
Where the model and reality disagree, reality wins and the book says so.

**The machine may not produce clean output.** Twenty spring-loaded channels
summing onto a knife-edge lever is an error-stacking nightmare. Calibration
could take longer than machining.

## Schedule

**I am learning machining from scratch for this project.** That is the point of
the [logbook](../../logbook/README.md), and it is the largest schedule risk.
A skill takes as long as it takes. *Mitigation:* the curriculum is sequenced so
each module ends by cutting a real part from the machine — progress is never
purely practice.

**Single point of failure.** One person, one shop, one seat. Illness or a
machine breakdown moves everything.

*Mitigation for both:* the dates on the campaign page carry deliberate slack,
and the manuscript is written continuously as parts are cut rather than in one
block at the end.

## Fulfilment

Print and shipping quotes are not yet in hand; see
[`../rewards/fulfilment.md`](../rewards/fulfilment.md). No physical reward goes
on the page without a confirmed unit cost and per-zone shipping.

## The donation

The finished machine is going to [Matemateca](https://matemateca.ime.usp.br/index_ingles.html)
at IME-USP, and the professor who runs the collection is enthusiastic about it.

Two things follow, and neither is optional.

**Get it in writing before their name appears on a commercial page.** A warm
email from an academic is not an institution consenting to appear in a
crowdfunding campaign, and a university's name on a page that takes money
carries an implication of endorsement that nobody has agreed to. Ask for
explicit written confirmation covering: that they accept the donation, that
their name and a link may appear on the campaign page, and how they want to be
described. If they would rather not appear until the machine is delivered,
that is a completely reasonable answer and the campaign works without it.

**The donation is a public promise, so it constrains the build.** A museum piece
operated by school groups has to tolerate handling that a builder's shelf model
never would: the amplitude bars get slid by teenagers, the crank gets turned
hard, and the wires that drive the pen can fly off the magnifying wheel if the
setup is done carelessly. That is a real design input, not a sentiment. Where it
conflicts with period fidelity, say which one won and why.

## Intellectual property {#ip}

**The machine is public domain.** Michelson and Stratton published in 1898;
Wm. Gaertner & Co. built them between 1896 and 1923. No live patent, no live
design right.

**The 2014 book is not.** *Albert Michelson's Harmonic Analyzer: A Visual Tour
of a Nineteenth Century Machine that Performs Fourier Analysis* by Bill Hammack,
Steve Kranz and Bruce Carpenter is © 2014 and distributed free **for
non-commercial purposes**. This project is commercial. Therefore:

- Every photograph and drawing in the commercial book must be original.
- No text from the 2014 book is reproduced.
- Dimensions derived by measuring published photographs are facts about a
  public-domain object, not expression — but the photographs themselves stay
  out of the commercial product.
- The 2014 book is cited generously as the source that made this possible, and
  readers are pointed to it.
- The reference material in `references/` (submodule) and the comparison
  gallery are **research inputs and open-source artefacts**, not campaign or
  book assets. Keep that boundary sharp: `cad/comparisons/ATTRIBUTION.md` covers
  the CC BY imagery in the open repo, not in a product for sale.

**Unresolved: which licence actually covers the book's photographs.**
`cad/comparisons/ATTRIBUTION.md` states that both the 2014 book and the video
series are published under **CC BY**, which would permit commercial reuse with
attribution. The book PDF's own front matter says something different: "© 2014
... All rights reserved" and "free for you to view and share for
**non-commercial** purposes". Those cannot both be right, and the difference
decides whether a single book photograph may appear anywhere near this campaign.

The engineerguy *videos* are CC BY with high confidence; the *book* is the
doubtful one, and the ch30 plates are book plates.

The README no longer depends on the answer. It used to pair a ch30 plate with
the CAD render; it now pairs a first-party photograph of the machine in its
display case with a render posed to match
(`cad/docs/images/real-machine-display-case.jpg`, and see that folder's README).
That closes the only place a book plate was doing load-bearing work in public.

*Action:* resolve it before launch anyway, because the book and the campaign
page still need to know.
1. Ask Bill Hammack directly. One email settles it, and it pairs naturally with
   the courtesy note below.
2. Until it is settled, keep book imagery out of anything that is itself for
   sale (the book interior, the campaign page, reward material).
3. If the answer is "non-commercial only", nothing has to be pulled, but every
   future figure has to be first-party. The photogrammetry set
   (`references/photogrammetry/raw/`, 90 captures from 2025-08-28) is close-ups
   through glass with a scale bar in frame, so it does not double as
   illustration; budget for a proper photo session, or use CAD renders.

*Action before launch:* a courtesy note to Bill Hammack. Not legally required;
obviously right, and he may well be a supporter. Fold question 1 above into it.

**This project is not affiliated with or endorsed by the authors of the 2014
book, engineerguy, or the University of Illinois.** Say so on the page.

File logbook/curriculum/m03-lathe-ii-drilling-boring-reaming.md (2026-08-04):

---
module: M03
title: "Lathe II — drilling, boring, reaming"
status: not started      # not started | in progress | competent | applied
hours_estimated: 16
hours_actual: 0
---

# M03 — Lathe II — drilling, boring, reaming

## Objectives

- Put a hole where you want it, at the size you want
- Bore to a running fit
- Ream to size

## Prerequisites

- m02

## References

- `references/machining-for-hobbyists-getting-started/06_chapter-4-drill-presses.pdf`
- `references/machining-for-hobbyists-getting-started/08_chapter-6-working-on-lathe.pdf`
- `references/machinerys-handbook/` (drill sizes, reaming allowances)

## Practice

- Centre drilling and why it is not optional
- Drilling on the lathe vs the mill
- Boring bar selection, deflection, spring passes
- Reaming allowance, speed and why you never reverse a reamer
- The 0.15 mm **diametral** running clearance used throughout this machine
  (Ø6.5 bore on a Ø6.35 shaft — 0.075 mm per side). Get this distinction right
  before you bore anything; halving it is a seized fit and doubling it is slop.

## Now make — the real part this unlocks

One **`pivot-bushing`**: Ø10.0 OD, Ø6.5 through bore, running on the Ø6.35 pivot shaft.

## Competency check

A bushing that turns freely on its shaft with no perceptible rock, measured not guessed.

## Notes

Boring to a *fit* is a different skill from boring to a *number*. Both are needed here.

## Sessions

Log entries for this module, newest last. Create them with
`entries/TEMPLATE.md`; **an agent may create the file, only you may fill it in.**

| date | entry | outcome | hours |
|---|---|---|---|
| | | | |

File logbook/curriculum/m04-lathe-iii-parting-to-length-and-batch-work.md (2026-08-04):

---
module: M04
title: "Lathe III — parting to length, and batch work"
status: not started      # not started | in progress | competent | applied
hours_estimated: 20
hours_actual: 0
---

# M04 — Lathe III — parting to length, and batch work

## Objectives

- Part off without the tool digging in
- Part to a LENGTH, repeatably, dozens of times
- Understand accumulated error across a set

## Prerequisites

- m03

## References

- `references/machining-for-hobbyists-getting-started/08_chapter-6-working-on-lathe.pdf`
- `cad/docs/machining-dfm.md` (pivot-bushing / lever-bushing rows)

## Practice

- Parting tool geometry, height, and rigidity — why parting scares beginners
- The collet stop: the whole trick for repeat length
- Measuring a stack rather than a part
- Batch discipline: one setup, one session, no mid-run tool changes
- Recovering (or not) from an undersize part

## Now make — the real part this unlocks

The full sets: **19× `pivot-bushing` at 4.5565 mm** and **19× `lever-bushing` at 4.0565 mm**. Do not mix the sets.

## Competency check

Nineteen bushings whose stacked length is within ±0.1 mm of 19 × nominal, and no single part outside ±0.02 mm.

## Notes

**This module decides whether the twenty channels line up.** Bushing length sets the 7.0565 mm channel pitch and the error accumulates nineteen times. It is the highest-leverage lathe skill in the project.

## Sessions

Log entries for this module, newest last. Create them with
`entries/TEMPLATE.md`; **an agent may create the file, only you may fill it in.**

| date | entry | outcome | hours |
|---|---|---|---|
| | | | |

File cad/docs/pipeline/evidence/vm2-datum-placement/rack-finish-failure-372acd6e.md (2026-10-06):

# Rack finish cold-reopen failure at 372acd6e

> Historical evidence: identifiers, paths, URLs and checksums below are retained as recorded. See [current subsystem identities](../../../subsystem-identities.md) for the canonical migration map.

The normal drawing build passed, but the complete rack lifecycle failed at its
first cold open. This head is not accepted for readable prints.

The [original lifecycle receipt](probes/rack-production-lifecycle-372acd6e/receipt.json)
has SHA-256 `94de73f21928ad2f707a5bbcf994037bb6fff759a95d22d3f59c888b18e56490`.
Its error says `datum/diameter ink clearance 0 m < 0.001 m`; the caller was
comparing the **finish leader against the datum**, not the diameter dimension.
The shared diagnostic error wording does not identify that caller.

The finish still has exactly one edge attachment, native equality 1, is not
dangling, and reads `Ra 1.6`. Its endpoint is
`(0.21804349740134313, 0.17344369111470476, 0.0015)` metres, at the crowded
datum location. Attachment alone does not prove clearance.

The subsequent [point/rebuild/cold-reopen experiment](probes/rack-production-lifecycle-372acd6e/finish-persistent-trial.json)
has SHA-256 `c25160bf30d218d77691c48606b84c831244f857343e77b4bd3ef627a49e0fe3`.
The endpoint remains at that location after rebuild and cold reopen, while
semantic attachment remains intact. The earlier immediate-only trial did not
prove persistence; the production helper's claim that its route persists is
not supported by this later experiment. A correction and fresh cold-print
validation are still required. These tried call sequences do not establish
that all native placement methods fail.

Source SHA-256 remained
`24eb4236303c758016d2340bd6cfbee63ffed63e2f5a73bfb99f889adbaac418` and the
saved production drawing remained
`d6f6920616a1bbb1e04ea4db3b205b71678e0938cb9354458f8015523a3177aa`.
The original production drawing is published with its
[normal-build receipt](probes/production-372acd6e/receipt.json).
The experimental drawing copy was subsequently saved by the point trial, so
it is not presented as the original failed drawing snapshot.

Raw receipts retain their exact bytes and local paths as the owner requested.
The exact probe source used by the point trial is archived beside its receipt.
No placement or manufacturing tolerance has changed. VM1's running combined
build remains frozen; even a green result does not clear this known failure.

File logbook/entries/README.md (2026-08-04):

# Entries

One file per session at a machine: `YYYY-MM-DD-<slug>.md`, from
[`TEMPLATE.md`](TEMPLATE.md).

**These are written by the person who did the work, at the machine or straight
after.** An agent may create the file from the template and tidy formatting
afterwards; it may not write the observations. Every feed, speed, measurement
and failure in the book traces back to an entry here, so a fabricated entry
would poison the whole book.

## What makes an entry useful later

- **The numbers you actually used**, not the ones you meant to use.
- **The failures, in full.** A scrapped part with the reason is worth more than
  three successes.
- **Time.** Real hours per part is the number the book publishes and the
  Kickstarter timeline is built on. Nobody else has it.
- **What surprised you.** You only get to be a beginner once, and that
  perspective is the book's whole edge.

## Conventions

- Frontmatter `outcome` is one of `success` · `partial` · `scrapped` ·
  `aborted`. Don't invent others — [`../progress.md`](../progress.md) counts
  them.
- Name the module in frontmatter so the module's session table can be updated.
- Raw photos and video go outside the repo (`logbook/media/` is gitignored);
  link them. Only frames destined for the book get committed, into
  `book/figures/hand/`.

## Index

_No entries yet._

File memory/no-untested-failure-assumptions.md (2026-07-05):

---
name: no-untested-failure-assumptions
description: Don't design defensive fallbacks around unverified assumptions about SolidWorks/tool failure modes
metadata:
  type: feedback
---

When designing, do NOT bake in defensive workarounds or fallbacks predicated on an
**unverified** assumption that a tool (e.g. SolidWorks) will misbehave — e.g. "SW may drift
under-defined components on rebuild, so run checks in a locked pose / force lock for exports."
Assume things work fine; enforce the real checks on whatever is actually being built.

**Why:** speculative hedging adds complexity and special-casing for a failure that may never
occur, and obscures the clean design. The user rejected a plan that ran soundness gates in a
"locked pose" and forced-locked exports to avoid hypothetical free-pose flakiness.

**How to apply:** enforce all gates on the as-built artifact in its actual mode. If a failure
mode is real, *reproduce it empirically first*, then fix it with evidence — don't pre-engineer
around it. See [[fix-relations-last-resort]] (same spirit: don't reach for heavy
mitigations before they're justified).

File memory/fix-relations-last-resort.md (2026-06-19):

---
name: fix-relations-last-resort
description: "Pedro's CAD directive — never anchor sketches with \"fix\" relations; use semantic relations + driving dims; fix only for justified reference geometry"
metadata: 
  node_type: memory
  type: feedback
  originSessionId: ba03bcc4-d81e-4e71-bbc7-7926c9a87d29
---

Pedro directed (2026-06-12) that ALL `fix` sketch relations in CAD build scripts be replaced with semantic relations (coincident, collinear, merge, distance dims tied to the origin/features), not just the circle pattern.

**Why:** A fix relation nails an entity in absolute space — it hides why geometry is positioned where it is, breaks parametric intent (upstream dimension changes don't propagate), masks under-defined sketches (sketch turns black without real relationships), and makes models harder to edit predictably.

**How to apply:** When authoring or migrating sketches in [[harmonic-analyzer-project]], fully define via real relations + dimensions tied to the origin or other features. `fix` is acceptable only for: locking reference geometry / base features that genuinely shouldn't move (e.g. equation-driven curves with no dimension scheme), throwaway layout sketches, or temporary scaffolding while sorting other constraints — and any surviving `fix` in production scripts needs an inline justification comment. Migration plan: point-addressability in SolidworksMCP-python (suffix refs like `Circle_1.center`, reserved `origin`) + `_common.py` semantic rewrite.

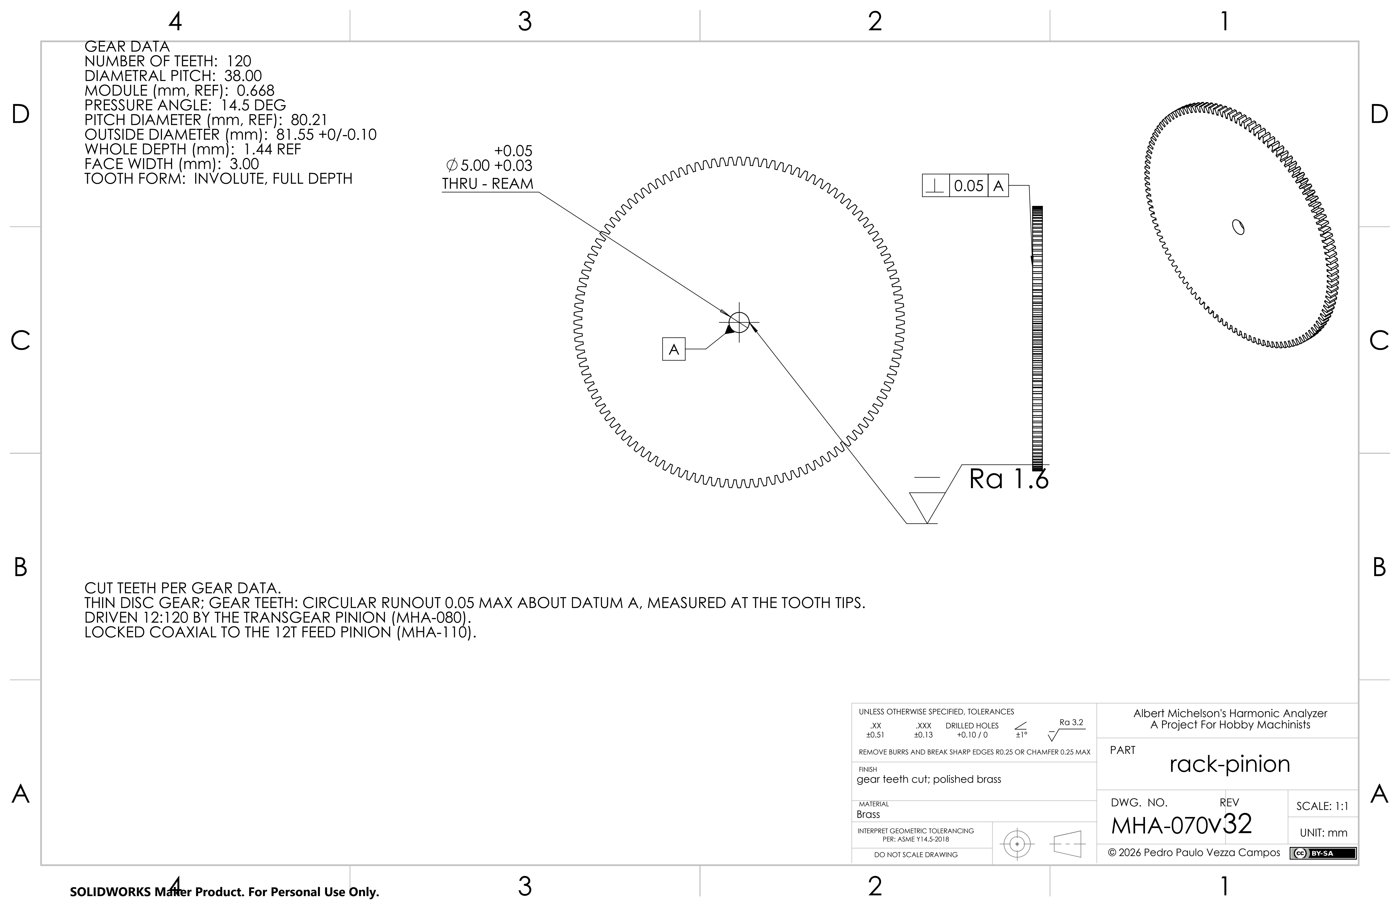
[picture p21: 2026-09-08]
cad/docs/pipeline/evidence/vm2-datum-placement/probes/production-184b6a76-visual-failure/rack-production-lifecycle-184b6a76/scaled.png

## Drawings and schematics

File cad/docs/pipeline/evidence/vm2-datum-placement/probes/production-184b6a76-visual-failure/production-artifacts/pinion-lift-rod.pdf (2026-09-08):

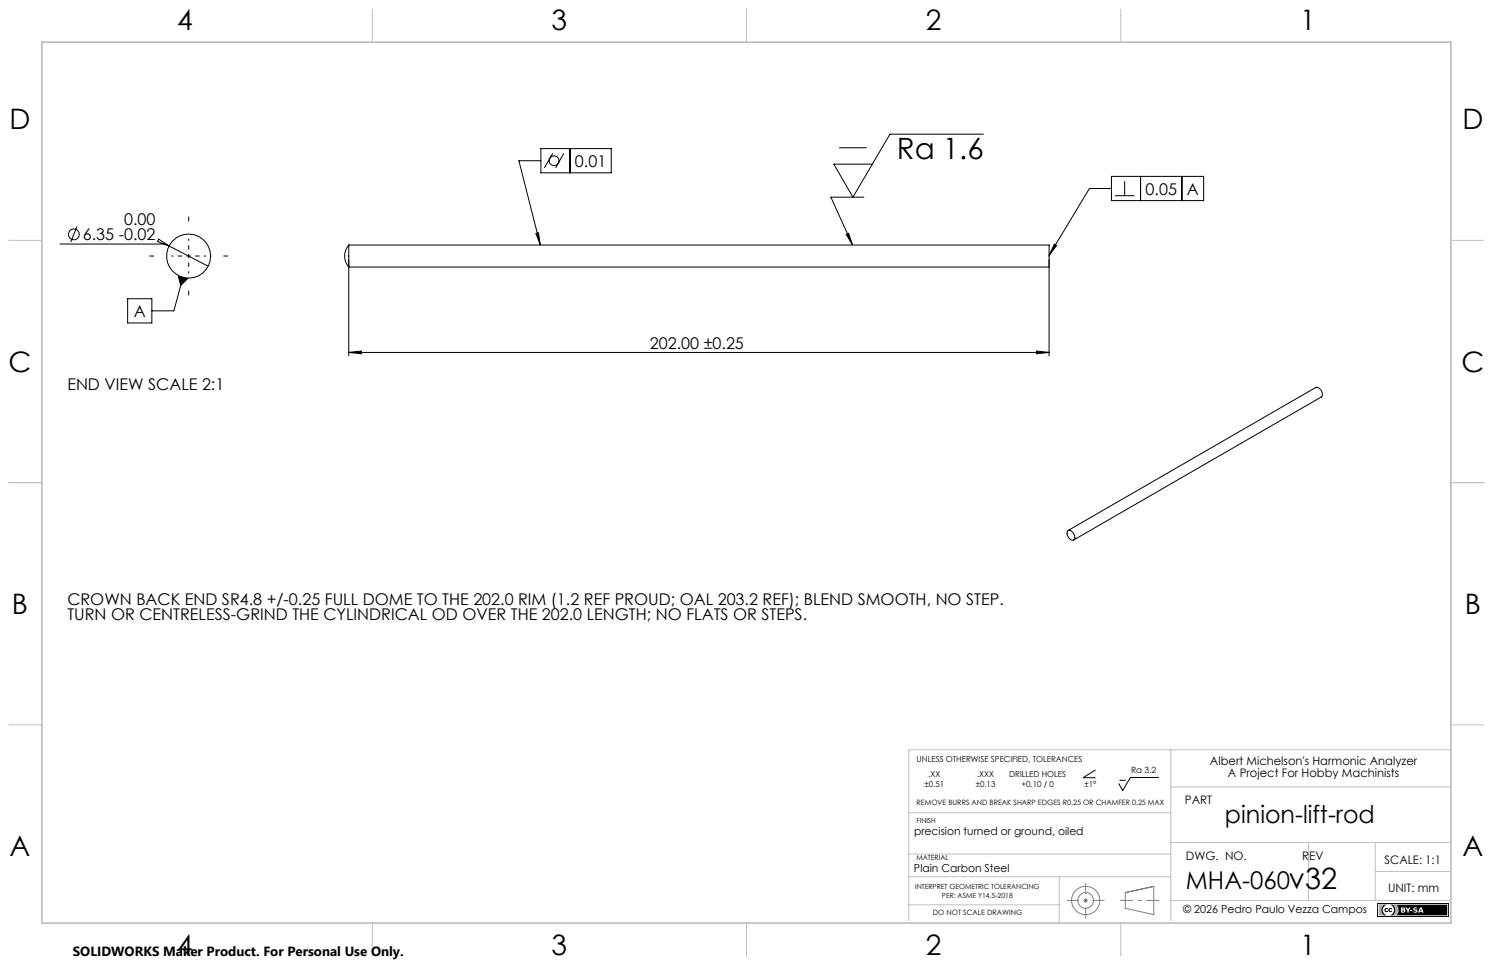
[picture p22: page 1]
Plain Carbon Steel; SCALE: 1:1 DWG. NO.; REV; PER: ASME Y14.5-2018; UNIT: mm; DRILLED HOLES +0.10 / 0

END VIEW SCALE 2:1

CROWN BACK END SR4.8 +/-0.25 FULL DOME TO THE 202.0 RIM (1.2 REF PROUD; OAL 203.2 REF); BLEND SMOOTH, NO STEP.
TURN OR CENTRELESS-GRIND THE CYLINDRICAL OD OVER THE 202.0 LENGTH; NO FLATS OR STEPS.

UNLESS OTHERWISE SPECIFIED, TOLERANCES

Albert Michelson's Harmonic Analyzer
pinion-lift-rod

A Project For Hobby Machinists Ra 3.2

REMOVE BURRS AND BREAK SHARP EDGES R0.25 OR CHAMFER 0.25 MAX
precision turned or ground, oiled

INTERPRET GEOMETRIC TOLERANCING

© 2026 Pedro Paulo Vezza Campos

DO NOT SCALE DRAWING

SOLIDWORKS Maker Product. For Personal Use Only.

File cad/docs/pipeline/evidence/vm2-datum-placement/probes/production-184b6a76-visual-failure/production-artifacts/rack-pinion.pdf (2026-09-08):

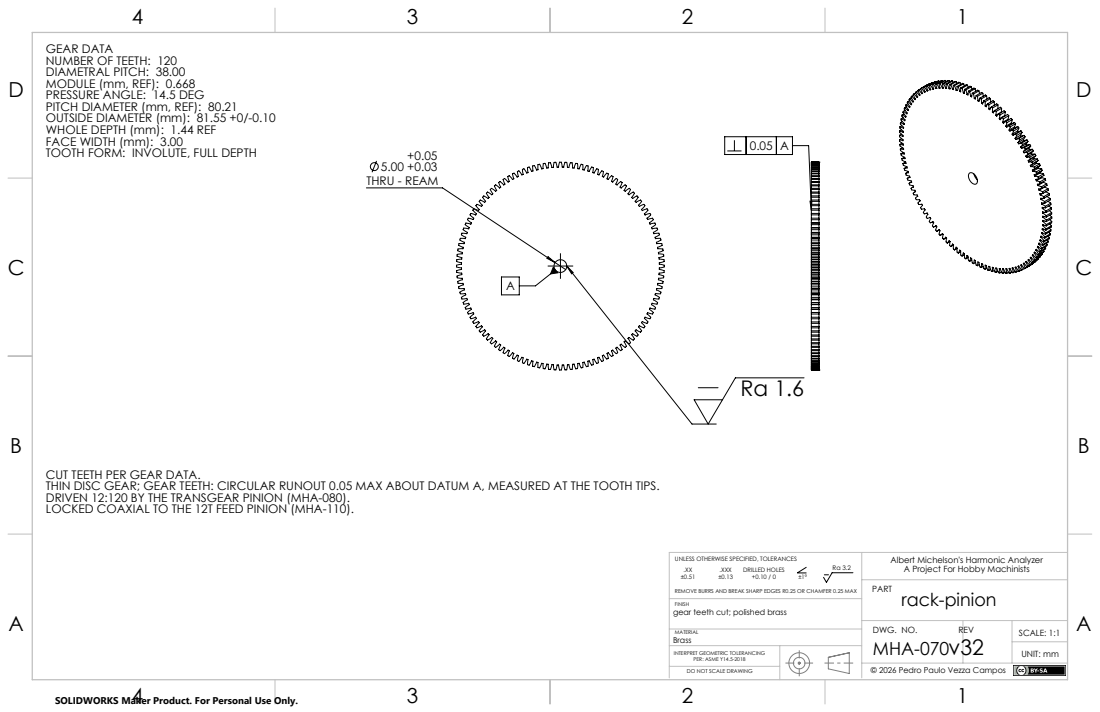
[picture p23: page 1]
THRU - REAM; SCALE: 1:1 DWG. NO.; REV; PER: ASME Y14.5-2018; UNIT: mm; DRILLED HOLES +0.10 / 0

GEAR DATA
NUMBER OF TEETH: 120
DIAMETRAL PITCH: 38.00
MODULE (mm, REF): 0.668
PRESSURE ANGLE: 14.5 DEG
PITCH DIAMETER (mm, REF): 80.21
OUTSIDE DIAMETER (mm): 81.55 +0/-0.10
WHOLE DEPTH (mm): 1.44 REF
FACE WIDTH (mm): 3.00
TOOTH FORM: INVOLUTE, FULL DEPTH

CUT TEETH PER GEAR DATA.
THIN DISC GEAR; GEAR TEETH: CIRCULAR RUNOUT 0.05 MAX ABOUT DATUM A, MEASURED AT THE TOOTH TIPS.
DRIVEN 12:120 BY THE TRANSGEAR PINION (MHA-080).
LOCKED COAXIAL TO THE 12T FEED PINION (MHA-110).

UNLESS OTHERWISE SPECIFIED, TOLERANCES

Albert Michelson's Harmonic Analyzer
rack-pinion

A Project For Hobby Machinists Ra 3.2

REMOVE BURRS AND BREAK SHARP EDGES R0.25 OR CHAMFER 0.25 MAX
gear teeth cut; polished brass

INTERPRET GEOMETRIC TOLERANCING

© 2026 Pedro Paulo Vezza Campos

DO NOT SCALE DRAWING

SOLIDWORKS Maker Product. For Personal Use Only.

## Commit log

2026-11-05 ch-jig: print the FlangeThick mate and keep the CskDia block inside the border (#2177)
    Farm run 20261105T010614057Z-91ba91430c2345388fde2df0993c4b07
    (52c67b0daa) passed every targeted leaf except the leadscrew kit's
    review, which had two gating findings on sheet 3:
    - The FlangeThick mate did not print. A line-broken ABOVE callout is
    stored and read back intact by GetText but never printed, the same
    known defect seven other drawings guard against. The callout is now
    one line, and import refuses a line break in any ABOVE rework callout.
    - The CskDia block crossed the right border: its shoulder runs right
    from the text point. The text point moves 16 mm left and the wall
    row now reads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
2026-11-05 ch-jig: make the FeedNut receipt and rework limits native (#2177)
    Codjiflo's fourth review of 3cec46c7d9 raised four P2s:
    - F2 opened the countersinks to Ø4.76, outside CskDia's Ø4.6 ±0.1
    (4475311242). CskDia is now a native LIMIT Ø4.76/4.50, with 4.76 the
    3/16 cutter rounded down. F2 opens within sheet 3's limits, and the
    heads stay proud: 0.05 min with a .191 head, 0.51 max.
    - The wall MIN rested on the nominal flange OD (4475311247). The OD
    now has a receipt band of Ø22 +/-0.2, and the walls are worst case at
    every limit: MIN WALL 0.40 TO BODY, 0.45 TO OD.
    - F1A typed its acceptance values (4475311251). ReceiptFlangeDia,
    ReceiptBodyDia, ReceiptHoleDia, ReceiptHolePcd and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
2026-11-05 ch-jig: move the FeedNut sheet-3 callouts clear of the part and their own lines (#2177)
    Farm run 20261105T023247678Z-e88a1e280b624d178e9b4a26f52ff544
    (13ce517b62) passed every targeted review except the leadscrew
    kit's, which raised two gating clarity findings. The one-arrow
    diameter and offset faced-length text blocks print centred on their
    text point, not starting from it:
    - The hole callout sat inside the Ø22 flange silhouette. The body,
    PCD and hole blocks now centre at x 0.205, clear of the rim and
    short of the section. The hole callout also gets its Ø
    (<MOD-DIAM>) and reads AS SUPPLIED.
    - The FacedLength text was crossed by its own dimension and extension
    lines. It now sits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
2026-11-05 ch-jig: let a callout's own line end just inside its text (#2177)
    Farm run 20261105T030845448Z-56ee4a9225e8427bacefb1d0ce681730
    (418537910c) passed every targeted review it reached. The new
    sheet-3 readback refused the kit drawing because CskDia's upper
    extension line runs 1.0 mm into its text. That placement is unchanged
    since run 11, whose reviewer passed it. The check now measures how
    far each line runs inside the text: the callout's own lines may run
    up to 1.5 mm in, while part outlines still count at any length. Run
    12's logged ink passes and run 11's two real crossings still fail.
    Checks: kit drawing, purchased and source-properties tests pass;
    ruff F821 clean.
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2026-11-05 ch-jig: show long kit members as an isometric only on sheet 1 (#2177)
    The final proof, farm run 20261105T035724094Z-6747f8d2eed44509b5dadd2b40a7e05c
    on 5bb2b81fcb, passed all 21 targeted reviews but one. The rail kit
    came back FIX: at 1:8 the Rail's sheet-1 orthographic views can't be
    read (a solid bar, filled dots, a speck), and sheet 2 redraws them
    anyway. The leadscrew kit's LeadScrew drew the same non-gating finding
    twice.
    build_purchased_variant_drawing takes an opt-in isometric_only
    {configuration: sheet}. Such a member gets one isometric filling its
    panel, headed 'QTY n INSTALLED, SEE SHEET k', and the readback
    accepts only that view. The Rail and the LeadScrew use it, and the
    clampi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
2026-11-05 ch-jig: follow main's inch strap band; enrol the lifecycle test (#2177)
    The rebase onto main 4e1ea07efc brings the inch rocker re-pin (#290):
    TOP_EDGE_BAND is now .020 in, so its half band is 0.254 rather than
    0.25. The carriage-play budget (0.050 + 0.112 shoulder term) still
    fits and now leaves 0.092. The test and the trammel docstring follow.
    Two conflicts were resolved in the trammel docstring (main's 1-1/2 in
    strap blank and the kit hardware line) and the 1173 stock note (main's
    54 in remainder and 2026-11-03 cut, with option B's unchanged bar
    length).
    Codjiflo P2 4476701306: test_reference_source_lifecycle.py ran in no
    check gate, so test_check_gate_enrollment flagged it as an orphan.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
2026-11-05 ch-jig: record the owner's FeedNut wall rulings; fix the rebased proof's three FIXes (#2177)
    Owner rulings 2026-11-04 (PR #2187 comment 6651067089, on the sketch in
    comment 6650871642), both 'Accept as owner exception': RV-01 for the
    0.40/0.45 mm countersink walls and RV-02 for the bought nut's 0.75 mm
    thread-to-body wall. Both reasons quote the ruling. The tests require
    it to cover the declared walls.
    Farm run 20261105T054045952Z-948177dc45494bb8bb5e80a6de115bf9
    (3fc52c9365, rebased onto main) passed all but three reviews, each with
    one gating clarity finding:
    - TL-32 feed block: the 'hidden-line dashes' over the outlines were
    construction lines in the reference sketches the drawing sho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
2026-11-05 ch-jig: freeze balloon 19 on the stud's near side (#2177)
    Why: farm run 20261105T070642635Z-9d22f4f89c84462a8c7f49d2254f2cbf failed
    drawing:ch_rocker_arm_tl_oblique_jig_assembly on swmaker000004: "jig rail
    bars exploded BOM coverage: sh-vn-clamping-kit-hardware--HoldDownStud
    frozen balloon anchor (-5.50, 56.13, -3.18) on ... HoldDownStud-3 is not
    its drawn ink: covered by ... -3". The stud stands upright (part +Z on
    the jig's -Y), so its rim point at 210 degrees has outward normal
    (cos, -sin, 0) . (1, -1, 1)/sqrt3 < 0 in the isometric: the far side, which
    the stud's own barrel covers. The offline replay models the stud as its
    envelope box and could not see that.
    What: STUD_RIM_DEG 210 -> 60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
2026-11-05 ch-jig: bound all four nut-hole clockings with a native TL-32 NutClock (#2177)
    Why: Codjiflo's review of b1709fb4ae on #2187.
    - 4477879822 (P2): receipt bounds the nut holes' PCD radius but not their
    angular spacing, and F1B clocked one hole, so an unequally spaced nut
    could put another transferred tap outside the 40-50 degrees the TL-32
    lug walls assume; the clearance-to-tap wall has 0.007 mm over the .060
    floor (RV-04).
    - 4477879826 (P2): the 45 deg +/-5 deg clocking was free text in F1B.
    What:
    - TL-32 NutPatternReference gains two construction rays from the leadscrew
    axis, along +Z and to the (-Y, +Z) tap centre, and NutClock, the driving
    angle between them: 45 deg with a nat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
2026-11-05 ch-jig: clear balloon 7 on its own shim stack; map kit member sources (#2177)
    Why: focused proof 20261105T163942818Z-9b01ea85 failed TL-00 at the
    plain-pivots leader readback. Balloon 7 lands on the top pivot shim of a
    stack of five 0.20 mm shims. Every point on that shim is within the 1 mm
    landing clearance of the shims under it: the stack side on the near
    half, and the far bore wall seen through its bore on the far half. The
    offline replay models each shim as a solid box, so it missed the bore.
    Codjiflo 4483623019: the identity map's current_source_files had no rows
    for the Amazon kit members' renamed specs, so source_aliases() and the web
    projection could not pair them with their sealed j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
2026-11-05 ch-jig: open the handwheel flat; bound the feed nut's faced length (#2177)
    Why: Codjiflo review 5789015665 on bc5ad1c02c raised two P2s that needed
    owner rulings. Both rulings are dated 2026-11-05 and recorded in PR #2187
    comment 6665347496.
    - 4483623004 (rule 4): the cut length and the flat stations and length
    had been tightened to .XX only so the closed handwheel flat kept a
    0.22 mm end land. Owner ruling, option B: the handwheel flat runs out
    through the cut end, and every band goes back to the title block's .X.
    - 4483623010 (rule 18): FacedLength printed only 13.8 MAX, so a nut faced
    short had no lower limit. Owner ruling: approve RV-03. FacedLength
    becomes a LIMIT 13.8/13.2, a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
2026-11-05 fr_harmonic_base: clear the near casting wall, thread only the far wall on the cross screws
    Why: owner ruling (Pedro, 2026-11-05) eliminates the special long-reach
    reduced-shank #10-32 tap the interrupted near+far wall thread required.
    On MHA-FR-01 fr_harmonic_base the near casting wall becomes a #10 close
    clearance (Ø.206, #5 drill) and only the far wall is tapped 10-32 UNF-2B,
    on all four cross-screw paths. Owner follow-up: MHA-FR-02 fr_top_frame is
    out of scope here and keeps its current both-walls tap bit-identical
    (fr_frame_attachment_spec is untouched, so its recipe key is unchanged).
    The screw stays MHA-FR-VN-53 (McMaster 90280A837 #10-32 x 1-3/4
    fillister); the MHA-FR-03 tube is unc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
2026-11-05 fr_harmonic_base: state the installed engagement acceptance as a ratio
    Codjiflo round 2 on #2209: a .285 MIN in MHA-FR-00 check 2 was a dimension
    in a free note (P2). The acceptance now asks for full-form far-wall
    engagement of at least 1.5 screw diameters, a ratio of the purchased screw,
    so no dimension lives in the note. Trace the new clearance-callout rewrite
    in its own span (P3).
2026-11-06 sh_vn_brass_fillister_screw: hide tangent edges in the orthographic views
    The v47 release run (origin/main 734cd4f98) failed check:machinist_review on
    this sheet with one confirmed gating clarity finding: the TOP 2:1 view
    carried faint grey dashed fragments (a dash at the head's left edge, one down
    the thread's right flank and one across the shank) used by no dimension,
    which rule 9 rejects. The views were already hidden-lines-removed; the dashes
    are the vendor body's split-face seams drawn as tangent edges.
    Hide tangent edges in Front/Top/Right through the purchased-sheet
    view_placement hook, read the setting back, and re-prove it at the final
    settled rebuild. Display only: no scale, posit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
2026-11-06 pd_platen: break section A-A's cut ends instead of closing them with object lines
    Machinist review on the v47 release run (origin/main 734cd4f98) returned FIX
    for pd_platen: the partial section A-A ended top and bottom in solid object
    lines, which a reader takes for the plate's own edges on a 5.31 in plate.
    Section A-A now keeps its partial cut (the floor reference still imports
    from it), then crops it with no outline to 5 mm either side of the hole and
    draws a thin long-break line with one Z on each trimmed end, the
    draw_ch_rocker_arm_tl_oblique_carrier pattern. The crop also drops the
    clip-screw boss that the cut's upper end showed beyond the plate. The floor
    value and the caption follo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
2026-11-06 pd_transgear_thumbnut: stand the countersink half-angle on its own arc
    Release v47's machinist review (734cd4f98, r2+r3) gated on Section A-A's
    45° countersink angle: its offset text hung on a leader that ran up past
    the arc's end and stopped loose in the hatching, touching neither the arc
    nor the flank.
    Drop the text offset. The native half-angle (still the imported model
    dimension, no typed value) is placed at its text point on the bisector of
    the axis/cone wedge, 27 mm out from the cone apex, so SolidWorks draws the
    arc through the text with no leader. At that radius the arc passes under
    the end of the Ø.18 diameter's right extension line instead of across the
    dimension line, and the t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
2026-11-06 dt_drive_train_assembly: fold steps 6-7 and check 7 into free fields, drop two near-empty sheets
    Why: the v47 release machinist review returned FIX on MHA-DT-00 (gating,
    rule 15): sheet 8 held only steps 6-7 and sheet 14 only check 7, each beside
    a large empty field, while sheets 7 and 13 broke their sequences just before
    free space.
    - Sheet 7's reference view moves under the left column (steps 1-3), so the
    right field runs the full height and carries steps 4-7.
    - Check 7 heads sheet 12's (was 13) right field, over the saved pose and
    interfaces; that sheet's reference view drops 7 mm to make room.
    - The CRANK and CHECKS (CONT.) sheets are gone: 15 -> 13 sheets. All in-package
    po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
2026-11-06 pd_transgear_thumbnut: clear the half-angle text from the Ø.18 extension end
    Iteration 1 (run 20261106T002837971Z, 42734b100) shipped 3/3, but its
    layout audit put the 45° text's corner 1.78 mm from the end of the Ø.18
    right extension line, under the 2 mm clearance. A 28.5 mm arc drops the
    text along the bisector to ~3.2 mm clear; the caption follows the arc's
    foot. Offline: test_pd_transgear_thumbnut_drawing.py 39 passed, ruff check.
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2026-11-06 fr_top_frame: clear the near casting wall, thread only the far wall on the cross screws
    Owner ruling (Pedro, 2026-11-05): repeat #2209 on MHA-FR-02. Each of the
    four fr_top_frame cross-screw paths gets a #10 close clearance (.206, #5
    drill) through the near casting wall from the counterbore floor; only the
    far wall keeps the 10-32 UNF-2B bottoming tap, so a standard-shank tap
    reaches it and the long-reach reduced-shank tap is gone.
    The shared joint contract (clearance, stock-screw reach, socket/far-mouth
    terms, 1.5D floor and installed check wording) moves to the new
    fr_frame_cross_screw module; fr_harmonic_base_fasteners imports it and
    drops its local copies. fr_frame_attachment_spec is un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
2026-11-06 draw_fr_top_frame: clearance callout above the view, near-side leader
    Run 20261106T172701582Z failed the layout audit: right of the tap the
    clearance leader ran through section label A, and the two rim-to-rim
    hole-callout leaders crossed at the shared centre.
2026-11-06 shop: record purchased Zoro taps and dies and owned kit
    Replace hypothetical kit identities with Pedro's photo-label contents and owner trust ruling; record paid Zoro order WB7365521946 dated 2026-11-06 without inventing physical measurements. Record the two owned kit tap wrenches, kit die handle and ordered Drillco stock; migrate all old illustrative wrench references.
    Verification: focused process shop/plans tests: 112 passed, 1 expected failure. Ruff check and format check pass for the changed regression test. Source-only check:recipe and check:config are running; final results will be recorded on the PR. No SolidWorks or full doit check group run.
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2026-11-06 ch-tl: trim kit rails flush with the base bars
    The owner requested flush rail ends. A one-ended trim leaves a sub-floor counterbore end wall, so shorten the purchased rails equally at both ends.
    Retain all eight mounting stations, shift the bar taps, and update native dimensions, drawings, fit-up instructions, inventory and regression contracts.
    Source-derived margins: 5.880 mm minimum counterbore end ligament and approximately 2.60 mm conservative carriage end margin. Offline and shared native/render/machinist proof pending on the completed stack.
2026-11-06 ch-tl: fit the far rail trim to actual bar length
    Codjiflo identified that equal actual end cuts move the fixed rail stations outside their receipt band for valid bar lengths.
    Set the near trim from the first existing hole and match the far end to the actual bar. Preserve station and bar tolerances and check their extreme combinations. Migrate receipt fixtures to model-owned three-place precision.
    Source-derived counterbore end walls remain 6.134 mm near and 5.880 mm far. Shared stack checks and native proof remain pending.
2026-11-06 ch-tl: keep rail receipt notes within the purchased footer
    The exact-source import gate rejected four part-specific lines because the purchased sheet reserves only three beside its general note. Keep the receipt acceptance and both-ends-flush requirement on the sheet; retain cutting instructions in the process plan.
    Fixes the observed footer_top refusal without changing its limit. Offline and native proof will use the restacked source.
2026-11-06 cad: clear the rail station label from the view
    The focused receipt-sheet layout gate found Station1 entering the FRONT view's reserved cell.
    Move the outside-start text three millimetres farther left at normal size and require the existing two-millimetre clearance in its regression.
    Evidence: source bounding boxes leave 2.39 mm clearance after the move. First-hole trimming and footer guards are unchanged; final native/render proof remains required.
2026-11-07 jig: clear native rail receipt witness lanes
    The measured Station2 tolerance block overlaps six later witness-line lanes, so the former Station1-only correction cannot pass the settled native audit.
    Place both short station labels outside the near-end witness, retain normal typography and the 2 mm guard, and cover all eight rows with the pinned native extent regression.
    Evidence: failed source 0c3ed359 task log, rail attempt 20261107T002231Z-1-4eb76c9d. Translated minimum cell clearance is 3.019 mm; changed-source native confirmation follows integration.
2026-11-07 jig: name the rail-station mate at its callout
    The exact 84d receipt sheet names the mating bar only in a detached footer, leaving the tight station controls unexplained where they are read.
    Name the base-bar tapped holes at the station flag and put the short Station1 arrows outside, retaining every proven text lane, native dimension and clearance guard.
    Evidence: rail PDF 7cfb6ebdcdabdb74507b1032a014647ee5cdc16dbfb0562075e7b099641436bd. Changed-source native and ENFORCE confirmation follow cohort integration.
2026-11-07 cad: fit trimmed rails to their actual base bars
    The owner's one-off jig should not depend on independent tight rail-station coordinates.
    Transfer the eight taps from each actual trimmed rail, retain paired orientation and flush ends, and print nominal stations as references. Replace the supplier-pitch receipt claim with physical wall and free-fit acceptance.
    Source changes only; the integrated stack offline, native, render and machinist gates remain pending.
2026-11-07 drawing: preserve rail references and define fit acceptance
    Native 26bb proof exposed a REF formatter overwriting metric units, and the rail-kit machinist gate found wall/travel instructions without pass criteria.
    Author and read back complete model-owned metric references, attach the flush-end requirement to the length dimension, and name the existing wall and full-pass acceptance checks.
    Evidence: retained 26bb native failure log and rail-kit ENFORCE FIX. Regressions added; integrated checks and changed-source native proof remain pending.
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2026-11-07 drawing: state the rail and base-bar walls explicitly
    Machinist review could not unambiguously decode the multi-part slash-separated wall note.
    Name each wall and the base-bar drawing directly, moving full-pass acceptance into the attached rail-length callout while retaining the three-line footer.
    Evidence: 4d782f88 rail-kit FIX1; unchanged wall floor and transfer route, targeted native re-proof follows.
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2026-11-07 drawing: clear the rail length text from its witnesses
    Native ink bounds showed the functional callout crossing its own extension line. Move the existing target right and up, preserving the wall/travel text and all collision guards.
    Evidence: 957501d1 native bounds and a negative-case regression; targeted proof follows.
2026-11-07 drawing: attach the rail wall requirement to its own features
    Owner-delegated ruling 2026-11-07 removes another part's wall specification and requires the rail receipt flag at the counterbores and ends.
    Attach concise A flags, print the authorized 2.0 mm minimum, name the enlarged profile VIEW A, and remove duplicate transfer wording without changing the rail geometry.
    Evidence: bf1c82f4 rail-kit FIX2 and Main ruling; targeted proof follows.
2026-11-07 cad: distinguish rail flag text lanes from leader extents
    Native note extents include attached leaders, so treating them as text-only falsely rejected the end-wall feature flags.
    Preserve text lanes and border checks while checking each leader against its intended feature and bounding its full envelope. Add the observed native box and refusal regressions.
    Evidence: rail task.log from 114c1622; full native binding audit and focused drawing reproof remain required.
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2026-11-07 logbook: 2026-11-05 session, both oblique-jig end brackets scrapped
    Pedro's 2026-11-05 shop notes, videos and recorded interview answers. He
    indicated the makerspace's 4 in vise to under 0.001 in, then tried the
    paper method and an edge finder, and laid out the length with a height
    gauge. He lost one end bracket when the 0.010 in jog step drove the cutter
    into the second blank. The other was lost to several drilling mistakes:
    no centre drill, no seating, and Z not re-zeroed after the drill change.
    - New entry, index row, progress roll-up, and M06/M01/M08 session rows.
    - Contact sheet of six frames from the session videos, in
    book/figures/hand/.
    - logbook rules: OneDrive media paths are al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
2026-11-08 ch-tl: simplify base bars and opposed bracket fastening
    The owner requested one drilled and one plain base-bar configuration, two shared-axis bracket holes and a common socket-head screw. Opposed 3/4 screws collide, so the approved KP08 second length is 5/8.
    Use Bar1 and Bar2 under one TL-20 identity with separate sheets and renders; use twenty 91251A197 screws and four 91251A196 screws, retire 91255A150, and propagate BOM, native references, travelers and tests.
    Owner ruling 2026-11-06 permits lower-bracket slip to positive bearing stops under abuse. The #12 clearance gives 0.876 mm reversal within 0.9; normal-feed slip, stop bearing/shear, thread engagement and tip separation remain guar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
2026-11-08 cad: preserve bar layout and fastener tolerance contracts
    The centred stations exposed a short-span extension-line collision and inherited tests tied to rounded stations, old wall distances and a single washer role.
    Move the near-slot text clear of the extension lines, derive the station and wall checks from printed limits, compute stop float directly from the maximum hole and minimum screw major, and scope the washer contract to the lever joint.
    Evidence: repairs the five focused failures at 8a1a without relaxing the two-millimetre text clearance, rule-17 wall target or owner .9 mm reversal bound. Final integrated and native checks remain required.
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2026-11-08 jig: enforce thread semantics and explain counterbore limits
    Native thread import groups redundant notes differently, while the bar sheet does not explain the precision needed to preserve the intended bearing stop and screw reach.
    Accept the feature-derived one-to-two redundant-note population while checking the final callouts and absence of stray thread notes. Keep all four section-thread instances mandatory. Name full-head-float and reach functions without changing the proven counterbore geometry.
    Evidence: bracket failure 20261107T012646Z-1-c9a62f9d and base-bar PDF 5cb4b1793c1b83a313dddfbe8c1e9c6e0cb1b39538cb1fd2390cc9cc15b4c55e. Counterfactual .XX diameter/depth checks refuse both loa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
2026-11-08 cad: record the R4 bracket lost-motion ruling
    The owner-delegated R4 ruling accepts up to 1.06 mm reversal without requiring tighter jig manufacture.
    Retain the existing #12 joint geometry and its 0.876 mm prediction; update the accepted ceiling and direct assertions.
    No new checks run; integrated top-of-stack proof remains pending.
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
